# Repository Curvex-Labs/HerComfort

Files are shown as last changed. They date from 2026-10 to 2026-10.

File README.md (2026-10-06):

<p align="center">
  
</p>

# HerComfort

HerComfort is a wearable menstrual comfort and wellness solution designed to support women during emergencies, disasters, displacement, travel, relief-camp conditions, and other situations where access to conventional menstrual-care resources may be limited. During floods, earthquakes, evacuation, temporary shelters, or other emergency situations, women may have limited access to hot water, private resting spaces, continuous healthcare support, or convenient methods for managing menstrual discomfort. HerComfort aims to provide a portable, rechargeable, hands-free solution that combines controlled heating, vibration-based comfort, physiological monitoring, and local therapy control in a compact wearable belt.

The system integrates temperature monitoring, muscle-activity sensing, motion and posture awareness, BLE connectivity, and offline operation so that essential comfort functions can remain available even when continuous smartphone or internet access is not practical.
By combining wearable therapy, sensing, portability, and connected monitoring, HerComfort is intended to improve menstrual comfort, independence, and dignity for women in both everyday life and challenging emergency or disaster-response environments.

---

<p align="center">
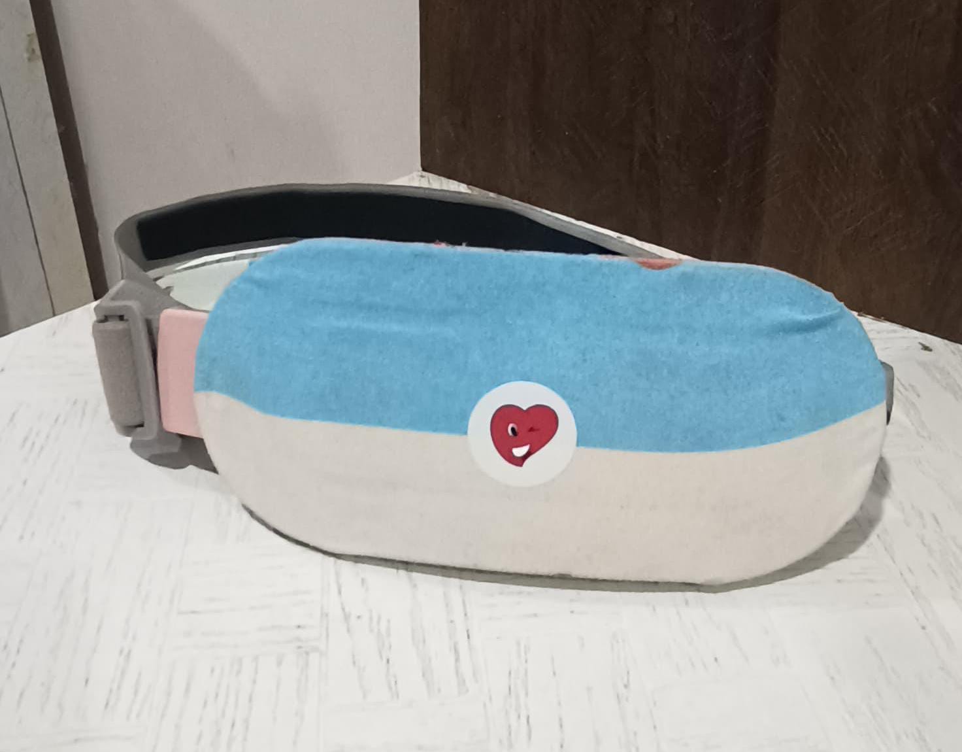
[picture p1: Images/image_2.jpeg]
  
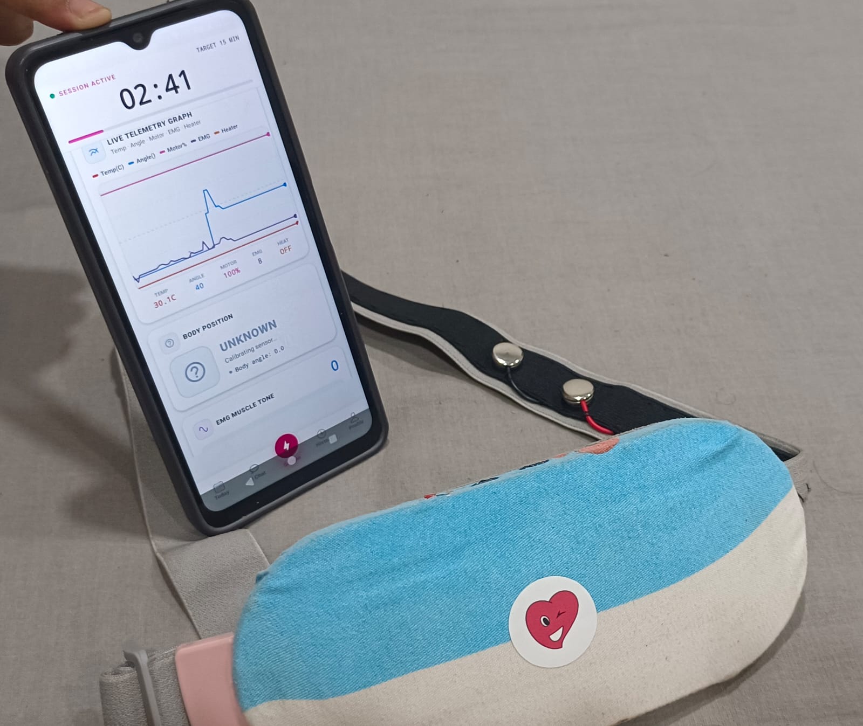
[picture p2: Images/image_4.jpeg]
  
</p>

<p align="center">
  <b>HerComfort Physical Prototype with Live Mobile Monitoring</b>
</p>

---

## Project Overview

HerComfort is being developed as an integrated wearable platform intended to support:

- Controlled heating therapy
- Vibration therapy
- EMG-based muscle activity monitoring
- Motion and posture sensing
- Temperature monitoring
- BLE connectivity
- Offline therapy control
- SOS / emergency support
- Battery-powered wearable operation

The final system is being designed around a compact custom PCB housed inside the curved front enclosure.

---

## Mechanical CAD Design

The refined HerComfort mechanical design was created in SolidWorks with a curved front therapy module, adjustable elastic belt, integrated controls, charging access, rear comfort surface, and dry EMG contact placement.

### Main Mechanical Dimensions

| Feature | Nominal Design |
|---|---|
| Therapy module | 185 mm long × 78 mm high |
| Maximum loft width | Approximately 80.1 mm |
| Overall depth envelope | Approximately 21.4 mm |
| Rear abdominal curvature | Approximately 3.5 mm sag across 160 mm |
| Rear comfort pad | Approximately 2.4 mm modeled section |
| Elastic strap | 48 mm wide × 3 mm thick |
| Charging opening | 10 × 3.8 mm USB-C access recess |
| Dry EMG contacts | Three 18 mm circular pads |
| EMG spacing | 30 mm center-to-center |
| Wearable circumference shown | Approximately 830 mm |

---

## Main CAD Views

### Front and Rear

<p align="center">
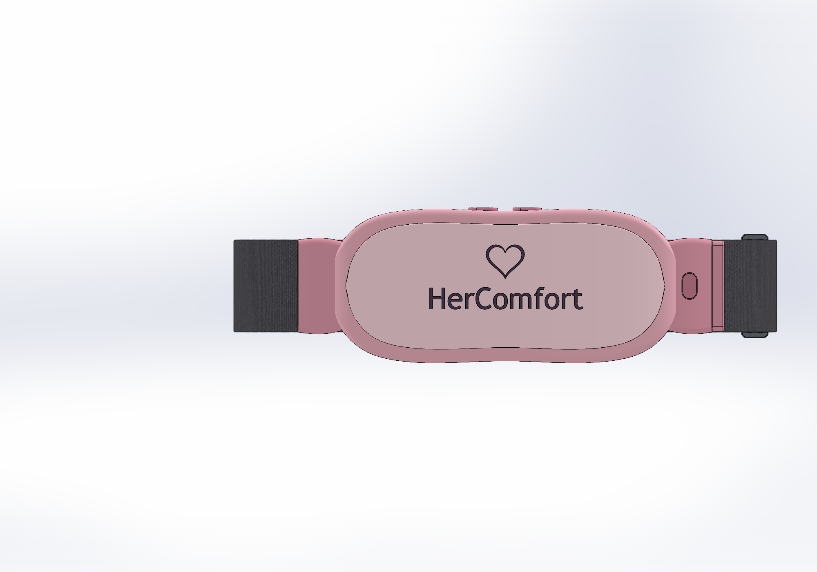
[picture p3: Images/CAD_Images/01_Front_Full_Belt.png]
HerComfort Front CAD View
  
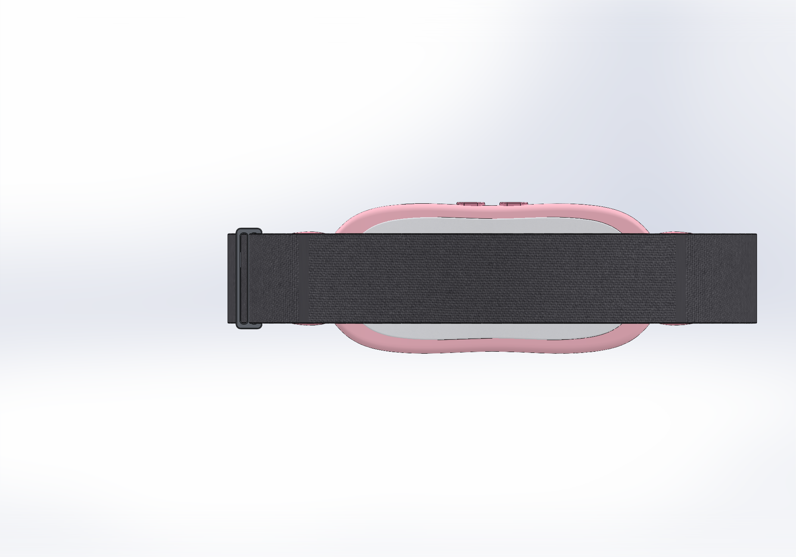
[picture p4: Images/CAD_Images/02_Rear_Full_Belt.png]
HerComfort Rear CAD View
  
</p>

### Isometric and Inner View

<p align="center">
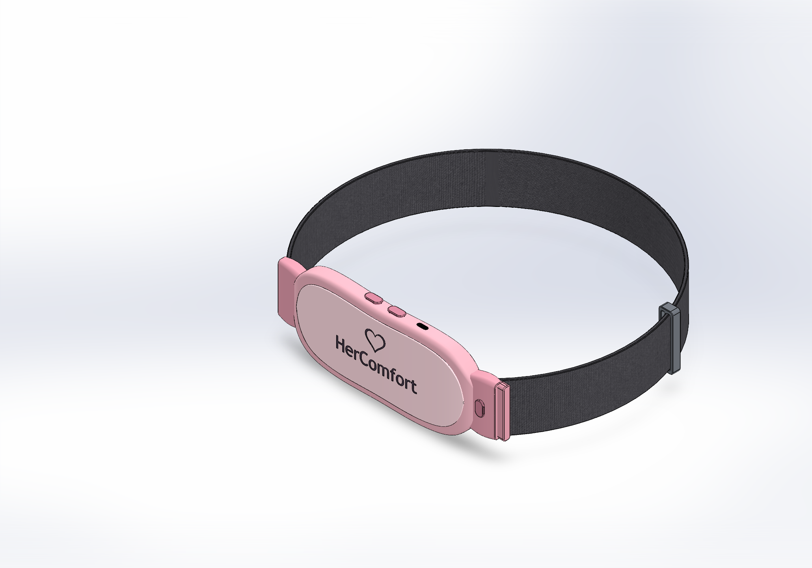
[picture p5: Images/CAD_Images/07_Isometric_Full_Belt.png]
HerComfort Isometric CAD View
  
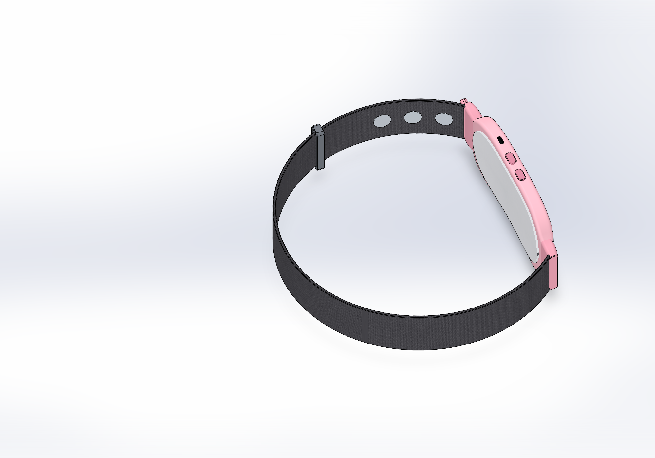
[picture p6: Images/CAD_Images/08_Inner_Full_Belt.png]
HerComfort Inner CAD View
  
</p>

---

## EMG Contact Design

HerComfort includes three dry EMG contact points on the skin-facing inner side of the belt.

The contacts are designed as:

- 18 mm circular metallic pads
- Arranged in one row
- 30 mm center-to-center spacing
- Positioned near the front-right inner belt region
- Integrated into the wearable surface

The intended signal chain is:

**Dry EMG electrodes → Muscle BioAmp Candy → Signal conditioning → ESP32-C6 ADC**

---

## Electronics Development

HerComfort currently uses a custom KiCad-designed carrier PCB that integrates the existing prototype modules into a compact and serviceable wearable electronics platform.

The present carrier board interfaces:

- Seeed Studio XIAO ESP32C6
- MPU6050 IMU
- Muscle BioAmp Candy
- DS18B20 temperature sensor
- TP4056 charging module
- Mini-360 DC-DC converter
- Heating pad
- Vibration motor
- AO3400A MOSFET switching stages
- Physical Mode button
- Li-ion battery

This carrier board represents the current functional prototype electronics.

A future fully integrated HerComfort PCB is planned to replace the removable modules with dedicated onboard circuitry and additional safety, sensing, power-management, and protection features.

---

## PCB Carrier Board

A custom HerComfort carrier PCB has been designed in KiCad to replace loose prototype wiring and provide a cleaner, compact hardware platform for the current working electronics.

The carrier board supports:

- Seeed Studio XIAO ESP32C6
- MPU6050 IMU
- Muscle BioAmp Candy
- DS18B20 temperature sensor
- TP4056 Li-ion charging module
- Mini-360 DC-DC converter
- AO3400A MOSFET heater control
- AO3400A MOSFET vibration motor control
- 1N5819 flyback protection diode
- Mode push button
- Heating pad connection
- Vibration motor connection
- Li-ion battery connection

The removable modules are mounted using female headers so that the controller and sensor modules can be replaced or serviced without replacing the complete PCB.
Images/PCB_Images/PCB_Back.png
### PCB Schematic

<p align="center">
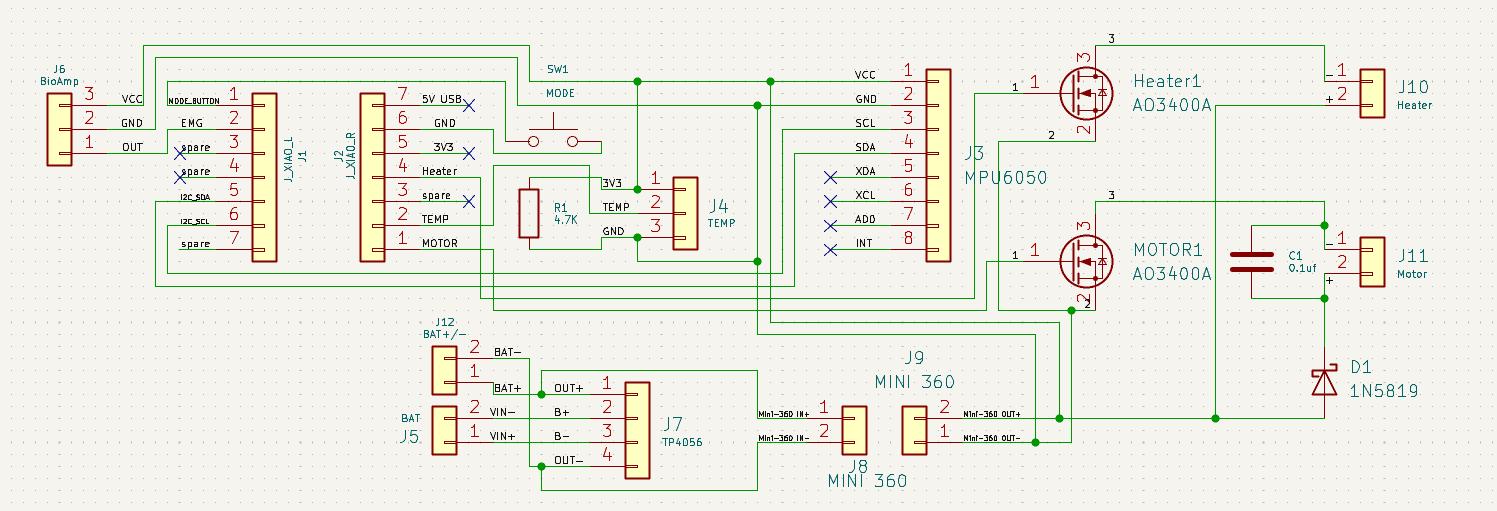
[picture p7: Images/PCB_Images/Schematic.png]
HerComfort PCB Schematic
  
</p>

### PCB Front and Back Views

<p align="center">
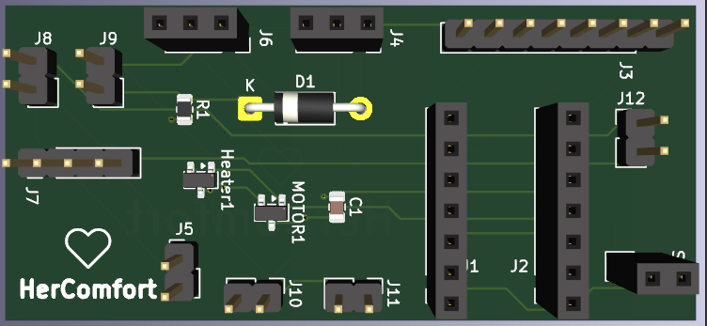
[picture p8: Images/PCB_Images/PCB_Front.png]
HerComfort PCB Front View
  
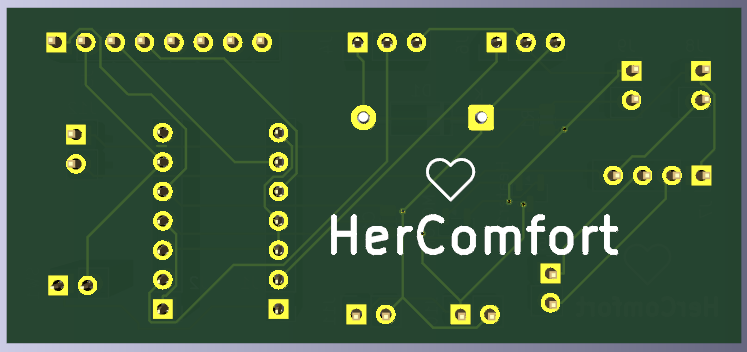
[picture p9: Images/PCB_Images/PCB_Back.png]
HerComfort PCB Back View
  
</p>

### PCB Routing

<p align="center">
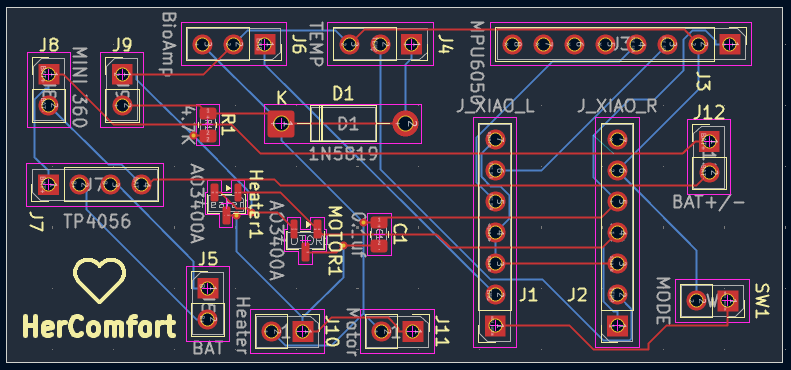
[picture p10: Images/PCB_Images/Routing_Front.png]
HerComfort PCB Front Routing
  
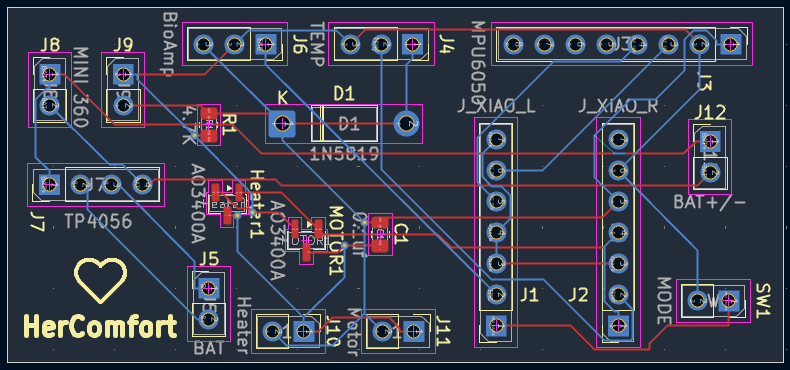
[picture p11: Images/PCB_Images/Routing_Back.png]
HerComfort PCB Back Routing
  
</p>

### Main GPIO Mapping

| Function | XIAO Pin | ESP32-C6 GPIO |
|---|---:|---:|
| Mode Button | D0 | GPIO0 |
| EMG Signal | D1 | GPIO1 |
| I²C SDA | D4 | GPIO22 |
| I²C SCL | D5 | GPIO23 |
| Vibration Motor | D7 | GPIO17 |
| DS18B20 Temperature | D8 | GPIO19 |
| Heating Pad | D10 | GPIO18 |

### Power Architecture

```text
3.7 V Li-ion Battery
        │
        ▼
      TP4056
        │
        ├────────► XIAO ESP32C6 battery input
        │
        ▼
     Mini-360
        │
        ▼
 Regulated therapy rail
        │
        ├────────► Heating Pad
        │
        └────────► Vibration Motor

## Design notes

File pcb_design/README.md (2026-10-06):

# HerComfort PCB Carrier Board

Custom raw carrier PCB developed for the HerComfort wearable menstrual comfort belt.

## PCB Overview

The carrier board integrates and connects the main HerComfort hardware modules:

- Seeed Studio XIAO ESP32C6
- MPU6050 IMU
- Muscle BioAmp Candy
- DS18B20 temperature sensor
- TP4056 Li-ion charging module
- Mini-360 buck converter
- AO3400A MOSFET heater control
- AO3400A MOSFET vibration motor control
- 1N5819 flyback diode
- Mode push button
- Li-ion battery
- Heating pad
- Vibration motor

## Schematic

HerComfort PCB Schematic

## PCB Front View

PCB Front

## PCB Back View

PCB Back

## Front Routing

Front Routing

## Back Routing

Back Routing

## Main GPIO Mapping

| Function | XIAO Pin | GPIO |
|---|---|---|
| Mode Button | D0 | GPIO0 |
| EMG | D1 | GPIO1 |
| I2C SDA | D4 | GPIO22 |
| I2C SCL | D5 | GPIO23 |
| Motor | D7 | GPIO17 |
| Temperature | D8 | GPIO19 |
| Heater | D10 | GPIO18 |

## Power Architecture

```text
Li-ion Battery
      |
    TP4056
      |
 Protected Battery Output
      |
      +---- XIAO ESP32C6
      |
      +---- Mini-360
               |
              3.3V
               |
        Heater + Motor

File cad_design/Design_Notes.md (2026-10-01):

# HerComfort refined external concept

This model follows the supplied correction brief and real product photos. It contains only exterior geometry. The screen in the reference product is deliberately omitted.

## Design dimensions (mm)

| Feature | Nominal design |
|---|---|
| Therapy module | 185 long × 78 high nominal; approximately 80.1 mm maximum loft width and 21.4 mm overall curved depth envelope |
| Abdominal curvature | Approximately 3.5 mm rear-pad sag across 160 mm |
| Rear comfort pad | 2.4 mm modeled section; approximately 1.6–2.3 mm exposed; gray textile appearance |
| Top controls | Two 15 × 8 mm pill buttons; approximately 1.7 mm exposed height |
| Button spacing | 8 mm clear gap |
| Charging opening | One 10 × 3.8 mm rounded USB-C access recess |
| Elastic strap | One continuous solid band, 48 mm wide × 3 mm thick |
| Wearable size shown | Approximately 830 mm circumference including the module |
| Connection | Fixed left anchor; right receiver, strap connector and raised release button |
| Adjustment | One simple two-slot slider |
| Dry EMG contacts | Three 18 mm circular silver pads on the inner front-right fabric |
| EMG sensing pair | 30 mm center-to-center along the strap centerline |
| EMG reference spacing | 30 mm from the nearer sensing pad; approximately 45 mm from the sensing pair midpoint |
| EMG contact profile | 1 mm total pad thickness, embedded into the 3 mm band; 0.35 mm maximum center projection; 0.25 mm edge fillets |

The main housing, front panel and contact pad use lofted sections with a gradual symmetric bow. The controls, connector details and slider use rounded sketches, extrusions and small fillets. The band is a single extruded curved profile behind the module.

Profile connection points are aligned consistently across each loft to preserve a clean capsule outline. The housing width adjusts slightly from the nominal sketch dimensions as the loft interpolates between sections.

## Verification

The final model rebuilt successfully. All 11 solid bodies returned zero errors from SolidWorks' body check. No feature errors were reported. The native and STEP exports both saved successfully with zero errors; the native save also reported zero warnings. The model includes centered HerComfort branding in muted plum on the lighter front panel. The editable wordmark and recreated heart use flush surface regions that follow the curved panel; they add no enclosure thickness. The branded model also rebuilt without feature errors and all 11 bodies passed the native body check. Native and STEP files saved with zero errors.

The six original views were inspected for the strap continuity, capsule outline, top controls, rear contact surface and detachable connector exterior.

## Files

- `HerComfort_Refined.SLDPRT`: editable SolidWorks 2024 multibody part with named modeling features.
- `HerComfort_Refined.step`: neutral solid geometry export.
- `Views/`: nine model views, including a front branding view, covering the front, rear pad, top controls, continuous band, detachable connection, abdominal curvature and inner EMG placement.
- `Appearances/`: rose finishes and gray fabric assets used by the native model. Keep these files together if moving the model. STEP primarily preserves geometry; use the native file for the intended appearance.

This is an exterior industrial design concept. The push-release connector and adjustment slider represent their visible form and connection arrangement. Their internal mechanisms, operation, structural performance, manufacturing clearances and heating performance are outside this model's scope.

## Inner dry EMG electrode update

The three contacts are separate editable solid bodies with a satin silver appearance. All three sit on the skin-facing side of the soft elastic band immediately beyond the right-hand pink connector. Their contact faces point inward toward the abdomen. All three pad centers lie on the middle of the 48 mm band width, forming one row along the curved inner fabric. Adjacent pads are evenly spaced at 30 mm center-to-center, leaving approximately 12 mm of fabric between their 18 mm diameters. The reference is approximately 45 mm from the sensing pair midpoint. This row replaces the previous triangular arrangement. Each pad remains tangent to its local inner fabric surface.

Each 18 mm pad is tangent to the local inner curve and extends into the fabric. Its central contact surface projects inward by 0.35 mm; projection reduces toward its rounded perimeter. The 1 mm pad remains within the strap thickness and does not emerge on the outside. The appearance represents a metallic contact surface; no wiring, sensors behind the contact, or electronics were modeled.

All 14 final solid bodies passed SolidWorks body checks with zero errors. No feature errors were reported. The native model and STEP geometry saved with zero errors, and the native save reported zero warnings. The recorded bounding boxes of all 11 pre-existing bodies match those before this update. Existing branding, colors, strap geometry, controls and proportions are preserved.

`Views/08_Inner_Right_EMG_Electrodes.png` shows all three contacts clearly beside the connector and control pod. `Views/09_Inner_Belt_EMG_Overview.png` verifies the contacts are on the inside of the wearable loop. These are exterior CAD contact representations; actual skin contact and EMG measurement performance were not tested.

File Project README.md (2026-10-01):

# HerComfort

<p align="center">
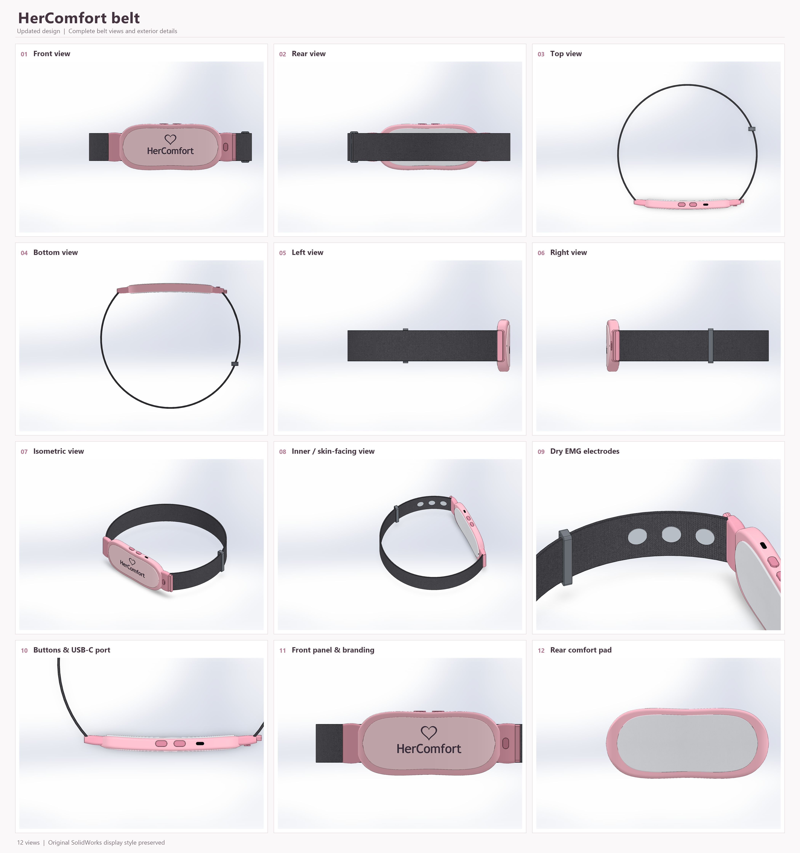
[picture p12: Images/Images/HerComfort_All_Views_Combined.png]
HerComfort Overview
  
</p>

HerComfort is a wearable health companion designed for menstrual comfort, physiological monitoring, local therapy control, and connected health support.

The project combines wearable mechanical design, custom electronics, sensing, therapy control, BLE connectivity, and embedded intelligence into a compact belt-based system.

---

## Project Status

HerComfort is currently under active development.

### Completed
- Refined wearable industrial design
- Curved front therapy/control enclosure
- Adjustable elastic belt architecture
- Dry EMG contact placement
- SolidWorks native model
- STEP export
- Multiple verified product views
- Mechanical body checks completed successfully

### In Progress
- Custom HerComfort main PCB
- Bare ESP32-C6 integration
- Integrated Muscle BioAmp Candy analog front-end
- Heating pad control
- Dual vibration motor control
- IMU integration
- Temperature sensing
- Battery charging and power management
- BLE firmware
- Mobile application integration

---

## Product Views

<p align="center">
  
  
</p>

<p align="center">
  
  
</p>

---

## Design Details

<p align="center">
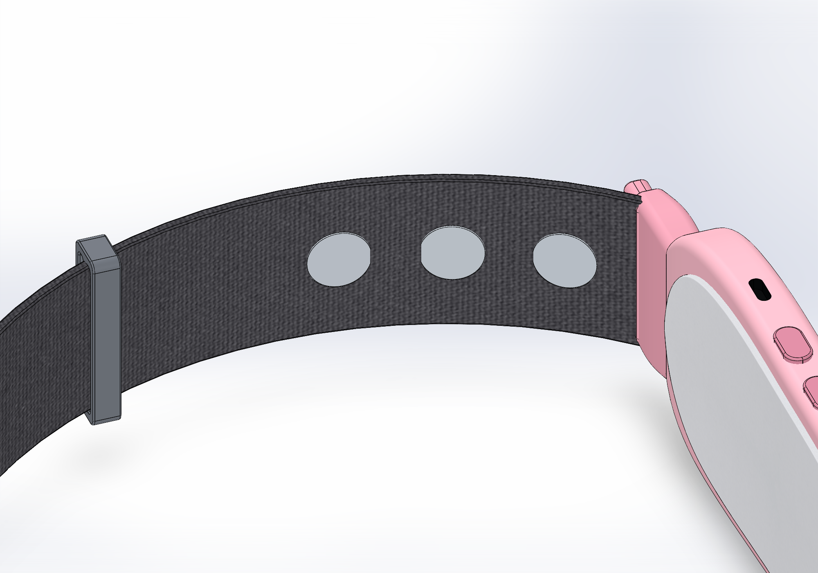
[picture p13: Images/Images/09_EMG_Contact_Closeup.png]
  
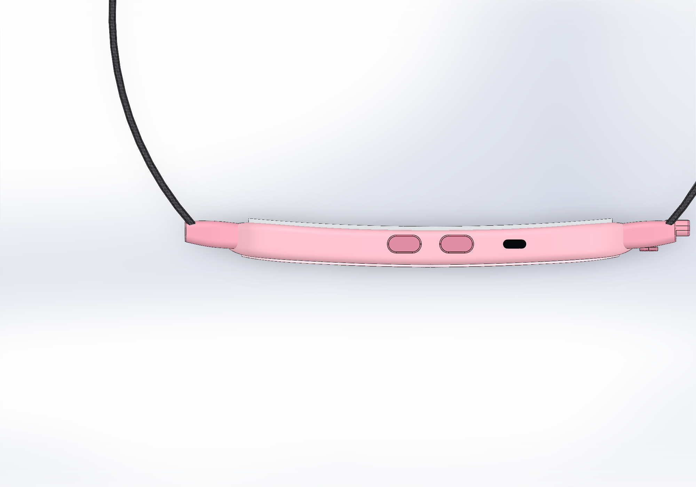
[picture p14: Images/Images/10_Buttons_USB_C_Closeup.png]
  
</p>

<p align="center">
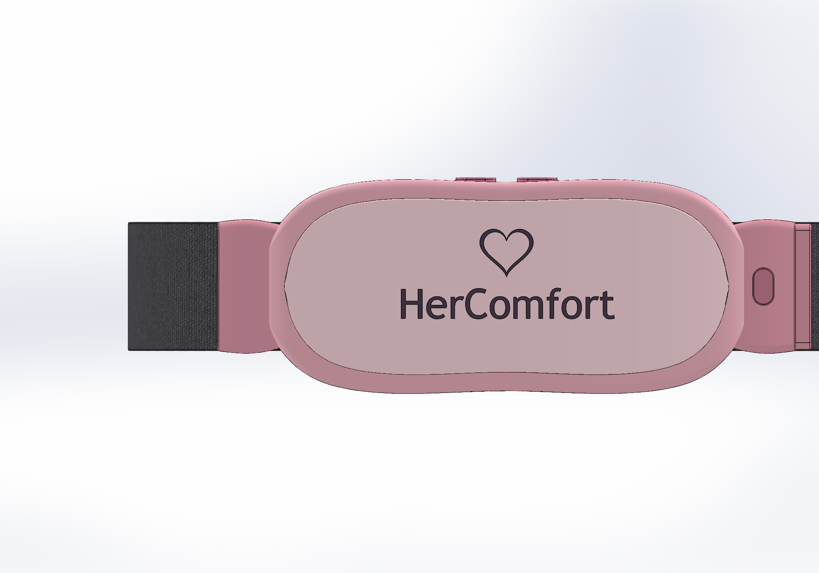
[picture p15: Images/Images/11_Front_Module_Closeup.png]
  
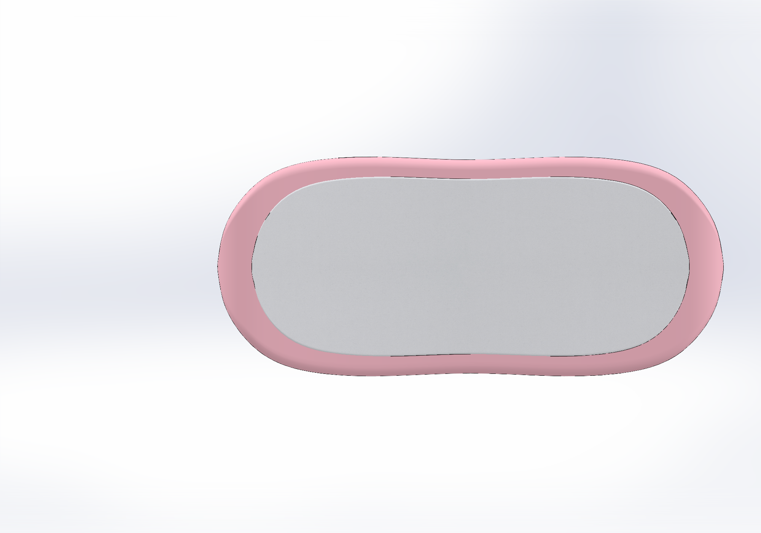
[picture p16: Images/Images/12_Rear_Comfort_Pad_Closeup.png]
  
</p>

---

## Mechanical Design

The current HerComfort model represents the refined external industrial design.

### Main Dimensions

| Feature | Nominal Design |
|---|---|
| Therapy module | 185 mm long × 78 mm high |
| Maximum curved width | Approximately 80.1 mm |
| Overall depth envelope | Approximately 21.4 mm |
| Rear abdominal curvature | Approximately 3.5 mm sag across 160 mm |
| Rear comfort pad | Approximately 2.4 mm modeled section |
| Strap width | 48 mm |
| Strap thickness | 3 mm |
| USB-C access opening | 10 × 3.8 mm |
| Dry EMG contacts | 3 × 18 mm circular pads |
| EMG spacing | 30 mm center-to-center |

The current enclosure model is primarily an exterior product-design concept. Internal electronics packaging, PCB mounting, battery space, and detailed internal mechanical clearances are being integrated alongside the electronics design.

---

## Dry EMG Contact Layout

HerComfort includes three dry EMG contact locations on the skin-facing side of the inner belt.

- Three circular metallic contact pads
- 18 mm diameter each
- Positioned in one row
- 30 mm center-to-center spacing
- Located immediately beside the right-side connector area
- Embedded into the inner elastic belt surface

The electrodes are intended to connect to the integrated EMG analog front-end on the main HerComfort PCB.

---

## Electronics Architecture

The final HerComfort system is intended to use one compact custom main PCB inside the front enclosure.

The PCB will contain or control:

- Bare ESP32-C6
- Integrated Muscle BioAmp Candy analog front-end
- 6-axis IMU
- Therapy-zone temperature sensing
- Heating pad driver
- Two independent vibration motor drivers
- Physical control buttons
- RGB/status indication
- USB-C charging and programming
- Battery protection
- Battery monitoring
- BLE communication
- Safety and fault-control circuitry

The ESP32-C6 acts as the central controller for the complete wearable system.

---

## EMG Front-End

The EMG section is based on the Muscle BioAmp Candy architecture and is being integrated directly onto the HerComfort main PCB.

The signal chain is:

**Dry EMG electrodes → input network → amplification → band-pass filtering → ADC conditioning → ESP32-C6 ADC**

The original Candy topology uses:

- Quad op-amp architecture
- Nominal gain around ×2420
- Band-pass range approximately 72–720 Hz
- Buffered reference voltage
- Differential EMG acquisition

The final integrated version is being adapted carefully for direct use with the ESP32-C6 ADC.

---

## Therapy System

HerComfort is designed to provide two forms of local therapy:

### Heating Therapy
A flexible heating pad is intended to provide controlled warmth to the lower-abdominal region.

The heating subsystem will include:

- Closed-loop temperature control
- PWM-based heater power control
- Temperature feedback
- Over-temperature protection
- Hardware safety cutoff
- Fail-safe OFF behavior

### Vibration Therapy
Two independently controlled vibration motors are planned for the therapy region.

Supported control modes may include:

- Continuous vibration
- Pulse vibration
- Variable intensity
- Patterned/harmonic vibration

---

## Physical Controls

The product is planned around three dedicated physical control functions:

1. Power
2. Offline Therapy
3. SOS / Emergency

The enclosure will be updated so the physical control geometry aligns directly with the PCB switches.

---

## Connectivity

HerComfort uses BLE communication for interaction with the mobile application.

Planned functions include:

- Therapy control
- Sensor monitoring
- Battery status
- Session information
- Device status
- Offline operation
- Emergency/SOS support

Essential local functions are designed to remain available without continuous internet connectivity.

---

## Power System

The power architecture is under active design.

The final battery selection will be based on:

- Heating-pad current
- Dual vibration-motor current
- ESP32-C6 peak consumption
- EMG analog front-end consumption
- IMU
- Temperature sensor
- BLE activity
- Power-conversion losses
- Required runtime

Battery capacity will be finalized only after the complete load budget is locked.

---

## Repository Structure

### `Mechanical/`
Contains the mechanical design files including:

- SolidWorks model
- STEP export
- Mechanical design assets
- Product geometry

### `Images/`
Contains:

- Front view
- Rear view
- Top view
- Bottom view
- Left view
- Right view
- Isometric view
- Inner belt view
- EMG contact close-up
- Button and USB-C close-up
- Front module close-up
- Rear comfort pad close-up
- Combined product view

### `Electronics/`
Will contain:

- KiCad project
- Schematic
- PCB layout
- BOM
- Gerber files
- Pick-and-place files
- PCB renders

### `Documentation/`
Will contain:

- System architecture
- Design specifications
- Electrical documentation
- Testing notes
- Development records

---

## Tools Used

### Mechanical
- SolidWorks 2024

### Electronics
- KiCad

### Embedded System
- ESP32-C6
- Embedded C/C++

### Communication
- Bluetooth Low Energy

---

## Development Notes

HerComfort is being developed as an integrated wearable system rather than a collection of separate development modules.

The design approach focuses on:

- Compact custom electronics
- Wearable comfort
- Reliable sensing
- Controlled therapy
- Low-noise EMG acquisition
- Safe power management
- BLE connectivity
- Manufacturable PCB design
- Enclosure-integrated electronics

---

## Current Development Roadmap

1. Finalize electronic components
2. Complete HerComfort schematic
3. Complete PCB placement and routing
4. Match PCB to enclosure geometry
5. Finalize battery and power architecture
6. Assemble prototype PCB
7. Validate sensing and therapy
8. Test BLE and offline control
9. Perform thermal and electrical safety testing
10. Refine for manufacturing

---

## Disclaimer

HerComfort is currently a prototype-stage engineering project.

The present mechanical model represents the product design concept and enclosure geometry. Electronic, thermal, sensing, and safety functions are still under development and validation.

The project does not claim medical certification or clinical diagnostic capability at its current stage.

---

## Team

Developed as part of the HerComfort wearable health project for innovation and prototype development.

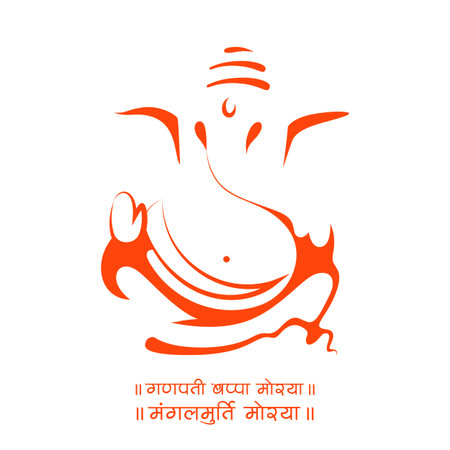
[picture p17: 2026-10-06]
pcb_design/Images/Lord_Ganesha.jpg

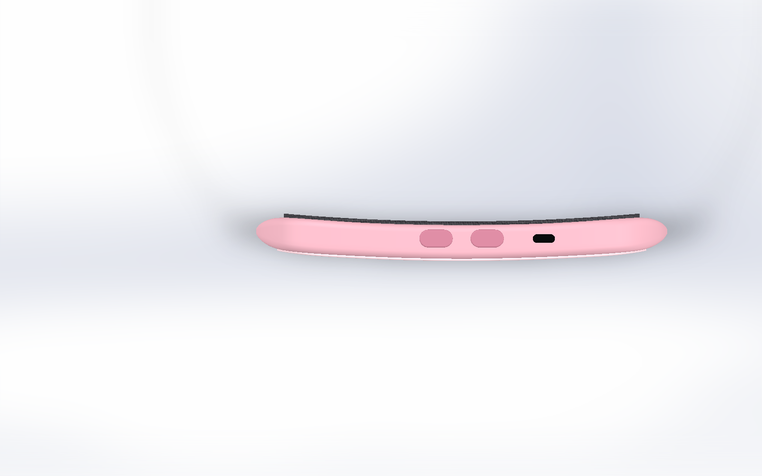
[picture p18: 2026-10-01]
cad_design/Views/03_Top_Buttons_USB_C.png

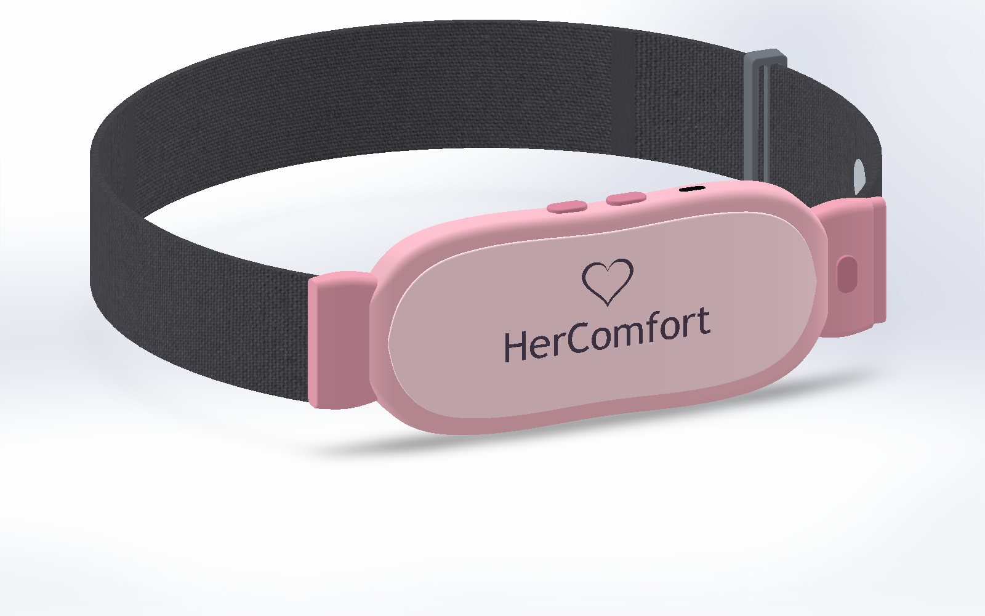
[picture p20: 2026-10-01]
cad_design/Views/01_Front_Isometric.png

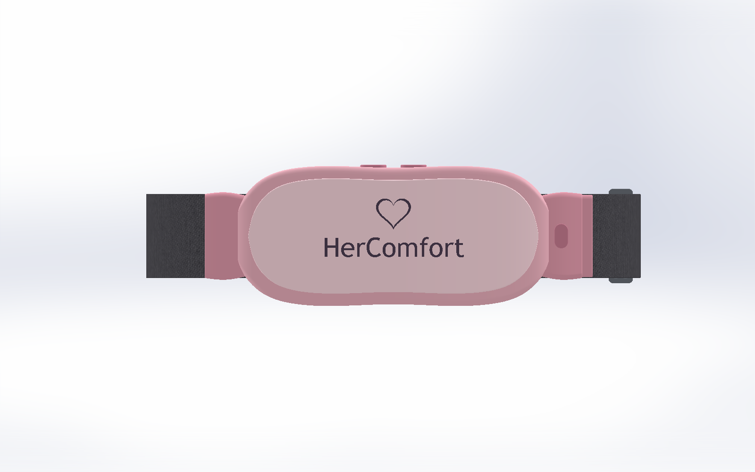
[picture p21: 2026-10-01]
cad_design/Views/07_Front_Branding.png

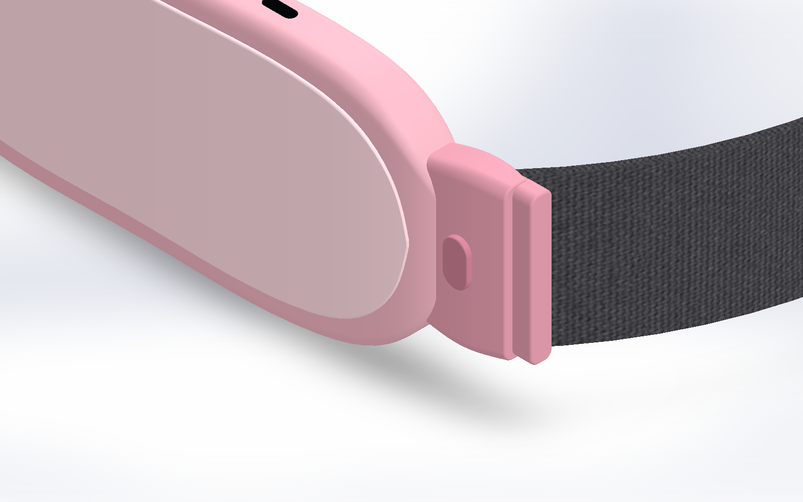
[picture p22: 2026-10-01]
cad_design/Views/05_Detachable_Connector_Closeup.png

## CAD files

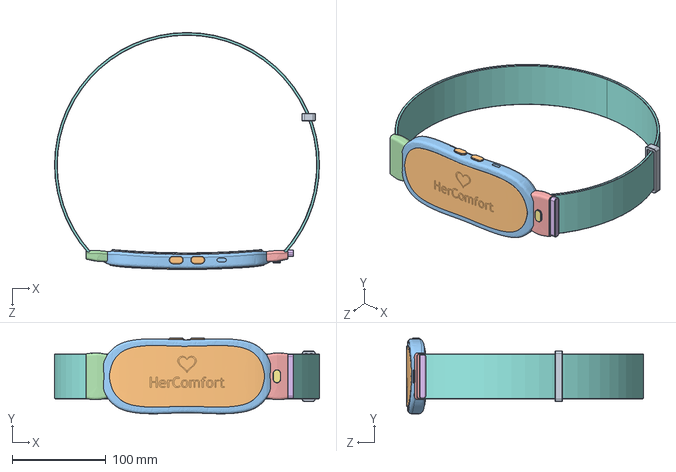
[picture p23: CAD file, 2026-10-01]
cad_design/HerComfort_Refined.step
283.0 x 80.7 x 253.2 mm

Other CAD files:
cad_design/HerComfort_Refined.SLDPRT

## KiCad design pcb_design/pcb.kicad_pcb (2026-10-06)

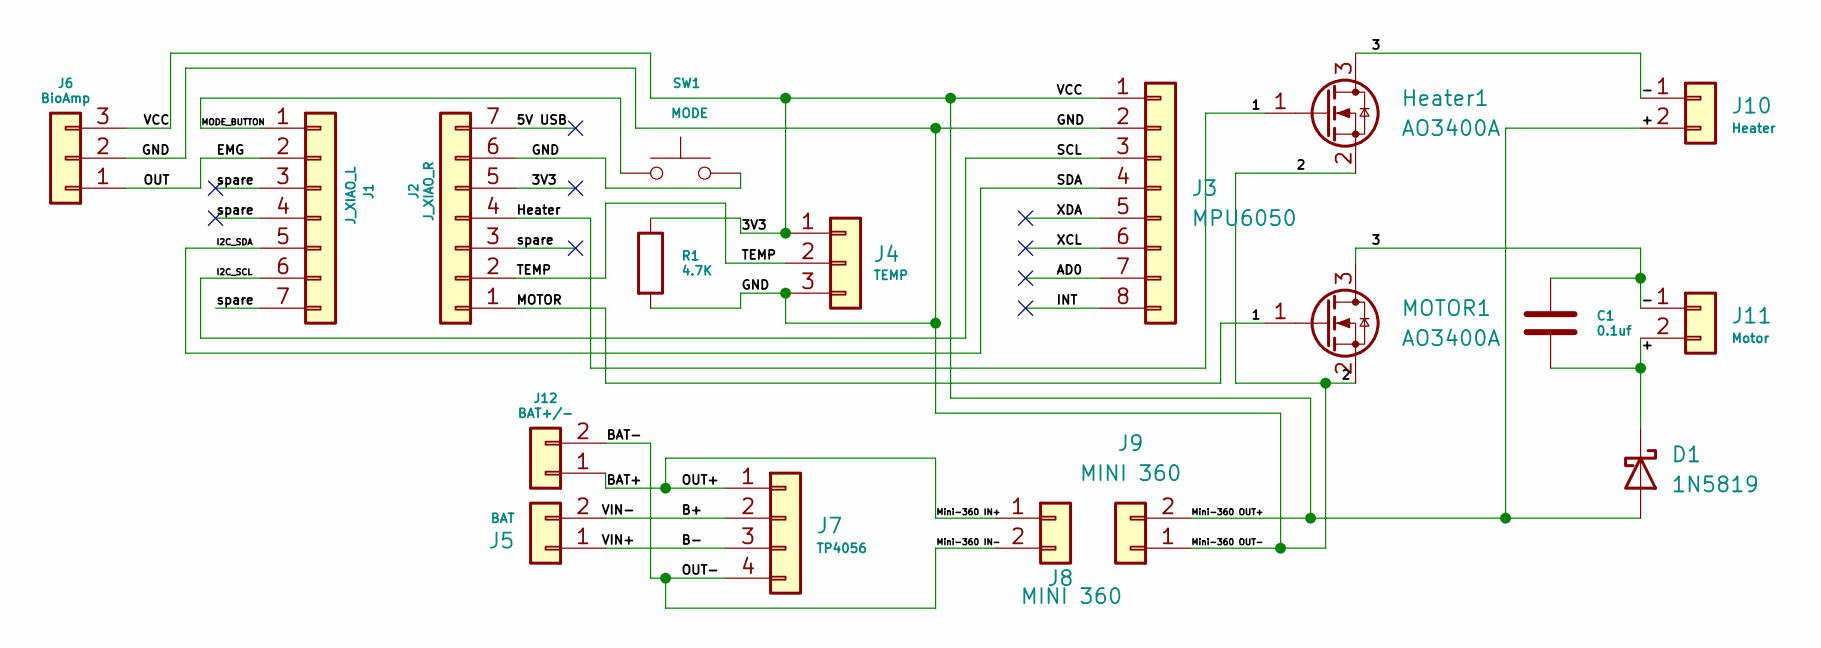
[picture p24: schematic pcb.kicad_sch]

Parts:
C1: 0.1uf; C_0805_2012Metric
D1: 1N5819; D_DO-41_SOD81_P10.16mm_Horizontal
Heater1: AO3400A; SOT-23
J1: J_XIAO_L; PinSocket_1x07_P2.54mm_Vertical
J2: J_XIAO_R; PinSocket_1x07_P2.54mm_Vertical
J3: MPU6050; PinHeader_1x08_P2.54mm_Vertical
J4: TEMP; PinSocket_1x03_P2.54mm_Vertical
J5: BAT; PinHeader_1x02_P2.54mm_Vertical
J6: BioAmp; PinSocket_1x03_P2.54mm_Vertical
J7: TP4056; PinHeader_1x04_P2.54mm_Vertical
J8, J9: MINI 360; PinHeader_1x02_P2.54mm_Vertical
J10: Heater; PinHeader_1x02_P2.54mm_Vertical
J11: Motor; PinHeader_1x02_P2.54mm_Vertical
J12: BAT+/-; PinHeader_1x02_P2.54mm_Vertical
MOTOR1: AO3400A; SOT-23
R1: 4.7K; R_0805_2012Metric
SW1: MODE; PinSocket_1x02_P2.54mm_Vertical

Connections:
/1: Heater1.1 (G), J2.1, J2.4, MOTOR1.1 (G)
/2: Heater1.2 (S), J2.6, J3.2, J4.3, J6.2, J9.1, MOTOR1.2 (S), R1.2, SW1.2
/5V USB: J2.7
/+: C1.1, D1.1 (K), D1.2 (A), J2.5, J3.1, J4.1, J6.3, J9.2, J10.2, J11.2, R1.1
/-: C1.2, Heater1.3 (D), J10.1, J11.1, MOTOR1.3 (D)
/AD0: J3.7
/B+: J5.2, J7.2
/B-: J5.1, J7.3
/BAT+: J7.1, J8.1, J12.1
/BAT-: J7.4, J8.2, J12.2
/EMG: J1.2, J6.1
/I2C_SCL: J1.6, J3.3
/I2C_SDA: J1.5, J3.4
/INT: J3.8
/MODE_BUTTON: J1.1, SW1.1
/TEMP: J2.2, J4.2
/XCL: J3.6
/XDA: J3.5
/spare: J1.3, J1.4, J1.7, J2.3

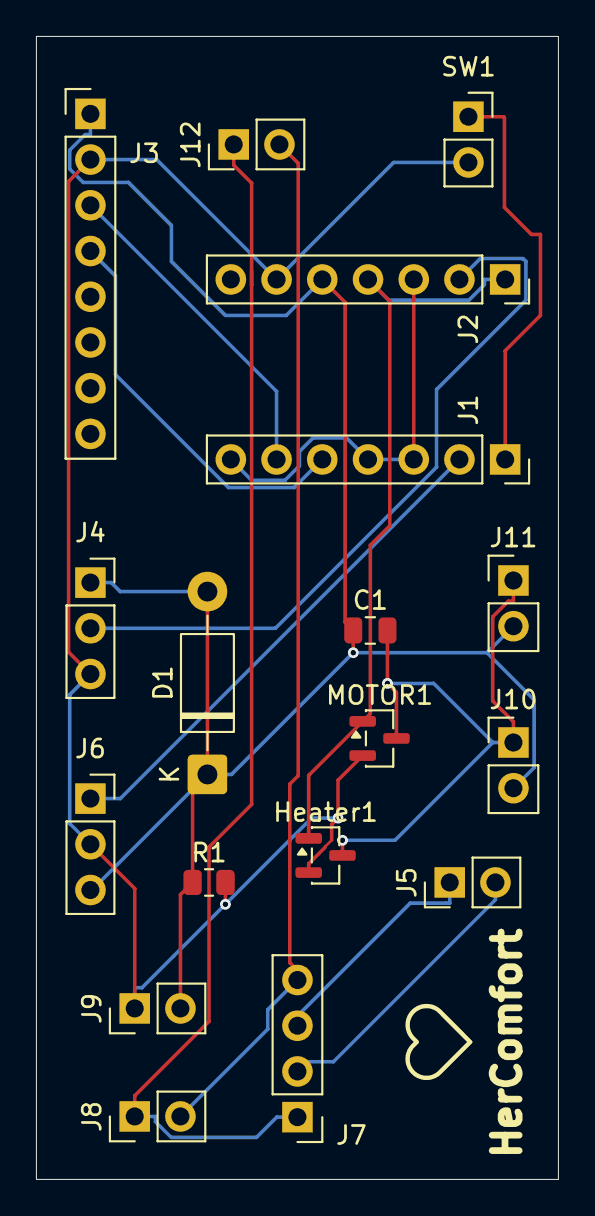
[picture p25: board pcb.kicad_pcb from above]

Board: 2 copper layers, 29.0 x 63.5 mm, 18 parts (0 on the bottom side), 14 nets.

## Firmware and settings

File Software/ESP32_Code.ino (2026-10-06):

#include <Arduino.h>
#include <Wire.h>
#include <math.h>
#include <NimBLEDevice.h>

#include <OneWireNg_CurrentPlatform.h>
#include <drivers/DSTherm.h>
#include <utils/Placeholder.h>

// =====================================================
// HER COMFORT - XIAO ESP32-C6
// =====================================================

// PIN MAP
#define MODE_BUTTON_PIN 0     // D0 / GPIO0
#define EMG_PIN 1             // D1 / GPIO1
#define SDA_PIN 22            // D4 / GPIO22
#define SCL_PIN 23            // D5 / GPIO23
#define MOTOR_PIN 17          // D7 / GPIO17
#define TEMP_PIN 19           // D8 / GPIO19
#define HEATER_PIN 18         // D10 / GPIO18


// =====================================================
// EMG
// =====================================================

#define EMG_SAMPLE_RATE 500
#define EMG_BUFFER_SIZE 128

int emgCircularBuffer[EMG_BUFFER_SIZE];
int emgDataIndex = 0;
long emgSum = 0;

int latestEMG = 0;

unsigned long lastEMGSample = 0;


// =====================================================
// HEATER
// =====================================================

const float HEATER_ON_TEMP = 37.0f;
const float HEATER_OFF_TEMP = 38.0f;

const float HEATER_HARD_CUTOFF = 40.0f;

bool heaterOn = false;


// =====================================================
// MOTOR
// =====================================================

#define MOTOR_PWM_FREQ 5000
#define MOTOR_PWM_RESOLUTION 8

const int CONTINUOUS_PWM = 255;
const int PULSE_PWM = 255;

const int HARMONIC_MIN_PWM = 200;
const int HARMONIC_MAX_PWM = 255;

const unsigned long PULSE_ON_TIME = 3000;
const unsigned long PULSE_OFF_TIME = 2000;

const unsigned long HARMONIC_PERIOD = 4000;

const unsigned long MODE_CHANGE_GAP = 1000;


// =====================================================
// MOTOR MODE
// =====================================================

enum MotorMode
{
  MOTOR_OFF,
  MOTOR_CONTINUOUS,
  MOTOR_PULSE,
  MOTOR_HARMONIC
};

MotorMode motorMode = MOTOR_OFF;


// =====================================================
// MOTOR STATE
// =====================================================

bool previousButtonState = HIGH;

unsigned long lastButtonPress = 0;

const unsigned long BUTTON_DEBOUNCE = 250;

unsigned long pulseTimer = 0;

bool pulseMotorOn = true;

unsigned long modeChangeTime = 0;

bool modeGapActive = false;

unsigned long harmonicStartTime = 0;


// =====================================================
// MPU6500
// =====================================================

#define MPU_ADDR 0x68

#define MPU_WHO_AM_I       0x75
#define MPU_PWR_MGMT_1     0x6B
#define MPU_CONFIG         0x1A
#define MPU_GYRO_CONFIG    0x1B
#define MPU_ACCEL_CONFIG   0x1C
#define MPU_ACCEL_CONFIG2  0x1D
#define MPU_ACCEL_XOUT_H   0x3B

#define MPU6500_ID 0x70


// =====================================================
// MPU SCALE
// =====================================================

const float ACCEL_SCALE = 16384.0f;

const float GYRO_SCALE = 131.0f;


// =====================================================
// MPU CALIBRATION
// =====================================================

const int CALIBRATION_SAMPLES = 1000;

float gyroBiasX = 0.0f;
float gyroBiasY = 0.0f;
float gyroBiasZ = 0.0f;

float referenceAx = 0.0f;
float referenceAy = 0.0f;
float referenceAz = 1.0f;

bool calibrationRunning = false;


// =====================================================
// ACCEL LOW PASS FILTER
// =====================================================

const float ACCEL_LPF_CUTOFF_HZ = 5.0f;

float filteredAx = 0.0f;
float filteredAy = 0.0f;
float filteredAz = 1.0f;

bool accelFilterInitialized = false;


// =====================================================
// SENSOR FUSION
// =====================================================

float q0 = 1.0f;
float q1 = 0.0f;
float q2 = 0.0f;
float q3 = 0.0f;

const float FUSION_KP = 0.40f;

const float FUSION_KI = 0.0f;

float integralFBx = 0.0f;
float integralFBy = 0.0f;
float integralFBz = 0.0f;

unsigned long lastFusionMicros = 0;


// =====================================================
// POSITION
// =====================================================

const float UPRIGHT_MAX_ANGLE = 45.0f;

const float LYING_MIN_ANGLE = 70.0f;


// =====================================================
// WALKING
// =====================================================

const float WALK_AXIS_THRESHOLD = 5.0f;

const float WALK_GYRO_THRESHOLD = 10.0f;

const float WALK_ACCEL_DELTA = 0.04f;


// =====================================================
// POSITION CONFIRMATION
// =====================================================

const unsigned long UPRIGHT_CONFIRM_MS = 1000;
const unsigned long LYING_CONFIRM_MS = 1500;
const unsigned long WALK_CONFIRM_MS = 700;


// =====================================================
// MPU RAW VALUES
// =====================================================

int16_t rawAx = 0;
int16_t rawAy = 0;
int16_t rawAz = 0;

int16_t rawGx = 0;
int16_t rawGy = 0;
int16_t rawGz = 0;


// =====================================================
// BODY ANGLE
// =====================================================

float latestBodyAngle = 0.0f;


// =====================================================
// POSITION ENUM
// =====================================================

enum PositionState
{
  POSITION_UNKNOWN,
  POSITION_UPRIGHT,
  POSITION_LYING,
  POSITION_WALKING
};

PositionState currentPosition = POSITION_UNKNOWN;

PositionState candidatePosition = POSITION_UNKNOWN;

unsigned long candidateStartTime = 0;


// =====================================================
// TEMPERATURE
// =====================================================

OneWireNg_CurrentPlatform oneWire(
  TEMP_PIN,
  false
);

DSTherm ds18b20(
  oneWire
);

Placeholder<DSTherm::Scratchpad> scratchpad;

float latestTemperature = 0.0f;

bool temperatureValid = false;

bool tempConversionRunning = false;

unsigned long tempConversionStart = 0;

unsigned long lastTempRequest = 0;

#define TEMP_CONVERSION_TIME 750


// =====================================================
// BLE
// =====================================================

#define SERVICE_UUID \
"12345678-1234-1234-1234-123456789000"

#define SENSOR_CHAR_UUID \
"12345678-1234-1234-1234-123456789001"

NimBLECharacteristic *sensorCharacteristic;

const unsigned long SEND_INTERVAL = 50;

unsigned long lastSend = 0;


// =====================================================
// MOTOR PWM
// =====================================================

void setMotorPWM(uint8_t pwm)
{
  ledcWrite(
    MOTOR_PIN,
    pwm
  );
}


// =====================================================
// MOTOR MODE NAME
// =====================================================

const char* motorModeName()
{
  switch (motorMode)
  {
    case MOTOR_OFF:
      return "OFF";

    case MOTOR_CONTINUOUS:
      return "CONTINUOUS";

    case MOTOR_PULSE:
      return "PULSE";

    case MOTOR_HARMONIC:
      return "HARMONIC";

    default:
      return "UNKNOWN";
  }
}


// =====================================================
// MOTOR MODE CHANGE
// =====================================================

void nextMotorMode()
{
  setMotorPWM(0);


  if (motorMode == MOTOR_OFF)
  {
    motorMode = MOTOR_CONTINUOUS;
  }

  else if (motorMode == MOTOR_CONTINUOUS)
  {
    motorMode = MOTOR_PULSE;
  }

  else if (motorMode == MOTOR_PULSE)
  {
    motorMode = MOTOR_HARMONIC;
  }

  else
  {
    motorMode = MOTOR_OFF;
  }


  modeChangeTime = millis();

  modeGapActive = true;

  pulseMotorOn = true;

  pulseTimer = millis();

  harmonicStartTime = millis();


  Serial.print("MOTOR MODE: ");

  Serial.println(
    motorModeName()
  );
}


// =====================================================
// BUTTON
// =====================================================

void updateMotorButton()
{
  bool currentButtonState =
    digitalRead(
      MODE_BUTTON_PIN
    );


  if (
    previousButtonState == HIGH &&
    currentButtonState == LOW
  )
  {
    if (
      millis() - lastButtonPress >
      BUTTON_DEBOUNCE
    )
    {
      lastButtonPress = millis();

      nextMotorMode();
    }
  }


  previousButtonState =
    currentButtonState;
}


// =====================================================
// MOTOR CONTROL
// =====================================================

void updateMotor()
{
  unsigned long now = millis();


  // MODE CHANGE GAP
  if (modeGapActive)
  {
    setMotorPWM(0);


    if (
      now - modeChangeTime <
      MODE_CHANGE_GAP
    )
    {
      return;
    }


    modeGapActive = false;

    pulseTimer = now;

    pulseMotorOn = true;

    harmonicStartTime = now;
  }


  // OFF
  if (motorMode == MOTOR_OFF)
  {
    setMotorPWM(0);

    return;
  }


  // CONTINUOUS
  if (motorMode == MOTOR_CONTINUOUS)
  {
    setMotorPWM(
      CONTINUOUS_PWM
    );

    return;
  }


  // PULSE
  if (motorMode == MOTOR_PULSE)
  {
    if (pulseMotorOn)
    {
      setMotorPWM(
        PULSE_PWM
      );


      if (
        now - pulseTimer >=
        PULSE_ON_TIME
      )
      {
        pulseMotorOn = false;

        pulseTimer = now;
      }
    }

    else
    {
      setMotorPWM(0);


      if (
        now - pulseTimer >=
        PULSE_OFF_TIME
      )
      {
        pulseMotorOn = true;

        pulseTimer = now;
      }
    }


    return;
  }


  // HARMONIC
  if (motorMode == MOTOR_HARMONIC)
  {
    float phase =
      (
        (now - harmonicStartTime) %
        HARMONIC_PERIOD
      )
      /
      (float)HARMONIC_PERIOD;


    float wave =
      (
        1.0f -
        cos(
          2.0f *
          PI *
          phase
        )
      )
      /
      2.0f;


    float pwmValue =
      HARMONIC_MIN_PWM +
      wave *
      (
        HARMONIC_MAX_PWM -
        HARMONIC_MIN_PWM
      );


    setMotorPWM(
      (uint8_t)pwmValue
    );

    return;
  }
}


// =====================================================
// HEATER
// =====================================================

void updateHeater()
{
  if (!temperatureValid)
  {
    heaterOn = false;

    digitalWrite(
      HEATER_PIN,
      LOW
    );

    return;
  }


  if (
    latestTemperature >=
    HEATER_HARD_CUTOFF
  )
  {
    heaterOn = false;

    digitalWrite(
      HEATER_PIN,
      LOW
    );

    return;
  }


  if (
    latestTemperature <=
    HEATER_ON_TEMP
  )
  {
    heaterOn = true;
  }

  else if (
    latestTemperature >=
    HEATER_OFF_TEMP
  )
  {
    heaterOn = false;
  }


  digitalWrite(
    HEATER_PIN,
    heaterOn ? HIGH : LOW
  );
}


// =====================================================
// MPU REGISTER WRITE
// =====================================================

bool writeMPURegister(
  uint8_t reg,
  uint8_t value
)
{
  Wire.beginTransmission(
    MPU_ADDR
  );

  Wire.write(reg);

  Wire.write(value);


  return (
    Wire.endTransmission() == 0
  );
}


// =====================================================
// MPU REGISTER READ
// =====================================================

uint8_t readMPURegister(
  uint8_t reg
)
{
  Wire.beginTransmission(
    MPU_ADDR
  );

  Wire.write(reg);


  if (
    Wire.endTransmission(false) != 0
  )
  {
    return 0xFF;
  }


  Wire.requestFrom(
    MPU_ADDR,
    1
  );


  if (
    Wire.available() < 1
  )
  {
    return 0xFF;
  }


  return Wire.read();
}


// =====================================================
// MPU INITIALIZATION
// =====================================================

bool initializeMPU()
{
  Serial.println();

  Serial.println(
    "Initializing MPU6500..."
  );


  Wire.begin(
    SDA_PIN,
    SCL_PIN
  );


  Wire.setClock(
    400000
  );


  delay(150);


  uint8_t whoAmI =
    readMPURegister(
      MPU_WHO_AM_I
    );


  Serial.print(
    "WHO_AM_I = 0x"
  );

  Serial.println(
    whoAmI,
    HEX
  );


  if (
    whoAmI != MPU6500_ID
  )
  {
    Serial.println(
      "WARNING: Expected MPU6500 ID 0x70"
    );
  }


  if (
    !writeMPURegister(
      MPU_PWR_MGMT_1,
      0x00
    )
  )
  {
    Serial.println(
      "ERROR: MPU6500 not responding"
    );

    return false;
  }


  delay(100);


  // Accelerometer +/-2g
  writeMPURegister(
    MPU_ACCEL_CONFIG,
    0x00
  );


  // Gyroscope +/-250 deg/sec
  writeMPURegister(
    MPU_GYRO_CONFIG,
    0x00
  );


  // Gyro low-pass
  writeMPURegister(
    MPU_CONFIG,
    0x03
  );


  // Accelerometer low-pass
  // Approx 10 Hz bandwidth
  writeMPURegister(
    MPU_ACCEL_CONFIG2,
    0x05
  );


  delay(100);


  Serial.println(
    "MPU6500 initialized."
  );


  Serial.println(
    "Accel vibration filtering enabled."
  );


  return true;
}


// =====================================================
// READ MPU
// =====================================================

bool readMPU()
{
  Wire.beginTransmission(
    MPU_ADDR
  );

  Wire.write(
    MPU_ACCEL_XOUT_H
  );


  if (
    Wire.endTransmission(false) != 0
  )
  {
    return false;
  }


  uint8_t received =
    Wire.requestFrom(
      MPU_ADDR,
      14,
      true
    );


  if (received != 14)
  {
    return false;
  }


  rawAx =
    ((int16_t)Wire.read() << 8) |
    Wire.read();

  rawAy =
    ((int16_t)Wire.read() << 8) |
    Wire.read();

  rawAz =
    ((int16_t)Wire.read() << 8) |
    Wire.read();


  // Skip internal temperature
  Wire.read();
  Wire.read();


  rawGx =
    ((int16_t)Wire.read() << 8) |
    Wire.read();

  rawGy =
    ((int16_t)Wire.read() << 8) |
    Wire.read();

  rawGz =
    ((int16_t)Wire.read() << 8) |
    Wire.read();


  return true;
}


// =====================================================
// ACTUATORS OFF
// =====================================================

void disableActuators()
{
  setMotorPWM(0);

  heaterOn = false;

  digitalWrite(
    HEATER_PIN,
    LOW
  );
}


// =====================================================
// CORRECTED SENSOR FUSION INITIALIZATION
// =====================================================

void initializeFusionFromReference()
{
  float rx = referenceAx;
  float ry = referenceAy;
  float rz = referenceAz;


  float mag =
    sqrt(
      rx * rx +
      ry * ry +
      rz * rz
    );


  if (mag < 0.1f)
  {
    q0 = 1.0f;
    q1 = 0.0f;
    q2 = 0.0f;
    q3 = 0.0f;

    return;
  }


  rx /= mag;
  ry /= mag;
  rz /= mag;


  // ==================================================
  // CORRECTED INITIAL QUATERNION
  //
  // Estimated gravity now starts aligned with the
  // calibrated upright reference.
  //
  // This avoids the temporary ~180 degree startup.
  // ==================================================

  if (rz > -0.999f)
  {
    q0 =
      sqrt(
        (1.0f + rz) *
        0.5f
      );


    float denom =
      2.0f *
      q0;


    // CORRECTED SIGNS
    q1 =
      ry /
      denom;

    q2 =
      -rx /
      denom;

    q3 =
      0.0f;
  }

  else
  {
    q0 = 0.0f;
    q1 = 1.0f;
    q2 = 0.0f;
    q3 = 0.0f;
  }


  // Normalize quaternion
  float norm =
    sqrt(
      q0*q0 +
      q1*q1 +
      q2*q2 +
      q3*q3
    );


  if (norm > 0.00001f)
  {
    q0 /= norm;
    q1 /= norm;
    q2 /= norm;
    q3 /= norm;
  }


  integralFBx = 0.0f;
  integralFBy = 0.0f;
  integralFBz = 0.0f;


  filteredAx =
    referenceAx;

  filteredAy =
    referenceAy;

  filteredAz =
    referenceAz;


  accelFilterInitialized =
    true;


  latestBodyAngle =
    0.0f;


  lastFusionMicros =
    micros();
}


// =====================================================
// MPU CALIBRATION
// =====================================================

void calibrateMPU()
{
  calibrationRunning = true;

  disableActuators();


  Serial.println();

  Serial.println(
    "======================================"
  );

  Serial.println(
    " HER COMFORT MPU6500 CALIBRATION"
  );

  Serial.println(
    "======================================"
  );


  Serial.println();

  Serial.println(
    "Wear belt normally."
  );

  Serial.println(
    "Sit or stand STRAIGHT."
  );

  Serial.println(
    "Keep completely STILL."
  );


  Serial.println();

  Serial.println(
    "Starting in 3 seconds..."
  );


  delay(3000);


  double axSum = 0;
  double aySum = 0;
  double azSum = 0;

  double gxSum = 0;
  double gySum = 0;
  double gzSum = 0;


  for (
    int i = 0;
    i < 100;
    i++
  )
  {
    readMPU();

    delay(5);
  }


  int validSamples = 0;


  while (
    validSamples <
    CALIBRATION_SAMPLES
  )
  {
    disableActuators();


    if (!readMPU())
    {
      continue;
    }


    float ax =
      rawAx /
      ACCEL_SCALE;

    float ay =
      rawAy /
      ACCEL_SCALE;

    float az =
      rawAz /
      ACCEL_SCALE;


    float gx =
      rawGx /
      GYRO_SCALE;

    float gy =
      rawGy /
      GYRO_SCALE;

    float gz =
      rawGz /
      GYRO_SCALE;


    axSum += ax;
    aySum += ay;
    azSum += az;

    gxSum += gx;
    gySum += gy;
    gzSum += gz;


    validSamples++;


    if (
      validSamples % 100 == 0
    )
    {
      Serial.print(
        "Calibration: "
      );

      Serial.print(
        validSamples / 10
      );

      Serial.println("%");
    }


    delay(4);
  }


  gyroBiasX =
    gxSum /
    validSamples;

  gyroBiasY =
    gySum /
    validSamples;

  gyroBiasZ =
    gzSum /
    validSamples;


  referenceAx =
    axSum /
    validSamples;

  referenceAy =
    aySum /
    validSamples;

  referenceAz =
    azSum /
    validSamples;


  float magnitude =
    sqrt(
      referenceAx * referenceAx +
      referenceAy * referenceAy +
      referenceAz * referenceAz
    );


  if (magnitude > 0.1f)
  {
    referenceAx /= magnitude;
    referenceAy /= magnitude;
    referenceAz /= magnitude;
  }


  initializeFusionFromReference();


  Serial.println();

  Serial.println(
    "CALIBRATION COMPLETE"
  );


  Serial.print(
    "Gyro bias: "
  );

  Serial.print(
    gyroBiasX,
    3
  );

  Serial.print(", ");

  Serial.print(
    gyroBiasY,
    3
  );

  Serial.print(", ");

  Serial.println(
    gyroBiasZ,
    3
  );


  Serial.print(
    "Upright reference: "
  );

  Serial.print(
    referenceAx,
    3
  );

  Serial.print(", ");

  Serial.print(
    referenceAy,
    3
  );

  Serial.print(", ");

  Serial.println(
    referenceAz,
    3
  );


  Serial.println(
    "Sensor fusion initialized."
  );


  calibrationRunning = false;
}


// =====================================================
// ACCEL LOW PASS FILTER
// =====================================================

void updateAccelLowPass(
  float ax,
  float ay,
  float az,
  float dt
)
{
  if (!accelFilterInitialized)
  {
    filteredAx = ax;
    filteredAy = ay;
    filteredAz = az;

    accelFilterInitialized = true;

    return;
  }


  float rc =
    1.0f /
    (
      2.0f *
      PI *
      ACCEL_LPF_CUTOFF_HZ
    );


  float alpha =
    dt /
    (
      rc +
      dt
    );


  alpha =
    constrain(
      alpha,
      0.0f,
      1.0f
    );


  filteredAx +=
    alpha *
    (
      ax -
      filteredAx
    );


  filteredAy +=
    alpha *
    (
      ay -
      filteredAy
    );


  filteredAz +=
    alpha *
    (
      az -
      filteredAz
    );
}


// =====================================================
// MAHONY SENSOR FUSION
// =====================================================
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
void loop()
{
  // EMG
  updateEMG();


  // BUTTON
  updateMotorButton();


  // MOTOR
  updateMotor();


  // TEMPERATURE
  updateTemperature();


  // HEATER
  updateHeater();


  // MPU
  updatePosition();


  // ==================================================
  // BLE + SERIAL
  // ==================================================

  if (
    millis() -
    lastSend >=
    SEND_INTERVAL
  )
  {
    lastSend =
      millis();


    String data = "{";


    // Temperature
    data +=
      "\"temperature\":";

    data +=
      String(
        latestTemperature,
        2
      );


    // Position
    data +=
      ",\"position\":\"";

    data +=
      positionName(
        currentPosition
      );

    data +=
      "\"";


    // Body Angle
    data +=
      ",\"bodyAngle\":";

    data +=
      String(
        latestBodyAngle,
        1
      );


    // Motor
    data +=
      ",\"motorMode\":\"";

    data +=
      motorModeName();

    data +=
      "\"";


    // Heater
    data +=
      ",\"heater\":\"";

    data +=
      heaterOn ?
      "ON" :
      "OFF";

    data +=
      "\"";


    // EMG
    data +=
      ",\"emg\":";

    data +=
      String(
        latestEMG
      );


    data +=
      "}";


    sensorCharacteristic->setValue(
      data.c_str()
    );


    sensorCharacteristic->notify();


    Serial.println(
      data
    );
  }
}

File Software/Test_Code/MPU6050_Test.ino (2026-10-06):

/*
  ================================================================
  HER COMFORT — MPU6500 POSITION & POSTURE ENGINEERING TEST FIRMWARE
  ================================================================
  Board:   Seeed Studio XIAO ESP32-C6
  IMU:     MPU6500 (I2C, addr 0x68)
  Pins:    SDA = D4 / GPIO22   SCL = D5 / GPIO23

  PURPOSE
  -------
  This is a CALIBRATION / VALIDATION tool, not a finished product.
  It answers one engineering question: can a single waist-mounted
  MPU6500 reliably separate Lying / Upright / Moving / Still, and
  can trunk-tilt posture be tracked over time?

  It does NOT measure spinal pressure, disc load, or any clinical
  quantity. All posture output is a relative, engineer-defined
  "Posture Load" indicator only — see calculatePostureLoad().

  DATA FLOW
  ---------
  MPU6500
    -> readMPU()                 raw accel/gyro registers
    -> calibrateGyro()           one-time zero-offset removal
    -> low-pass on accel         light smoothing on ax/ay/az
    -> calculateOrientation()    complementary filter -> pitch/roll
    -> updateMotionState()       gyro/accel magnitude -> moving/still
    -> classifyPosition()        candidate Lying/Upright/Moving/Still
    -> confirmPosition()         time-confirmed state (anti-flicker)
    -> classifyPosture()         deviation from calibrated neutral
    -> updatePostureTimer()      duration + hysteresis on posture
    -> calculatePostureLoad()    tilt x duration x movement factor
    -> printSerialData()         CSV line + event logs over Serial

  SERIAL COMMAND PROTOCOL (send as text line ending with \n)
  ------------------------------------------------------------
    CAL_GYRO         re-run gyro zero-offset calibration (keep still)
    CAL_NEUTRAL       calibrate neutral posture (hold correct posture)
    RESET             reset all duration timers and posture load
    START              begin logging/test run
    STOP                pause logging/test run
    MARK:SITTING        write an activity marker line to Serial
    MARK:STANDING
    MARK:LYING
    MARK:WALKING
    MARK:FORWARD_BEND
    MARK:LEAN_LEFT
    MARK:LEAN_RIGHT

  These are the same commands the companion web test-interface sends
  when you press its buttons.

  !!! ALL THRESHOLDS BELOW ARE PLACEHOLDERS !!!
  They are starting points only. Use the CSV log + MARK: events to
  compare known ground-truth activities against sensor output, then
  tune the CONFIGURATION block until states track reliably for you.
*/

#include <Wire.h>

// ================================================================
// PIN / DEVICE CONFIGURATION
// ================================================================
#define SDA_PIN 22          // D4
#define SCL_PIN 23          // D5
#define MPU_ADDR 0x68

// MPU6500 registers (compatible with MPU60x0 map)
#define REG_PWR_MGMT_1   0x6B
#define REG_SMPLRT_DIV   0x19
#define REG_CONFIG       0x1A
#define REG_GYRO_CONFIG  0x1B
#define REG_ACCEL_CONFIG 0x1C
#define REG_ACCEL_XOUT_H 0x3B
#define REG_WHO_AM_I     0x75

// Sensitivity for configured full-scale ranges.
// Accel is configured to +-2g -> 16384 LSB/g.
// Gyro is configured to +-250 dps -> 131 LSB/(deg/s), as specified.
const float ACCEL_LSB_PER_G   = 16384.0f;
const float GYRO_LSB_PER_DPS  = 131.0f;

// ================================================================
// CONFIGURATION — ALL VALUES BELOW ARE PLACEHOLDERS.
// They must be tuned against real recorded data (see MARK: events
// and the CSV log). None of these are medically validated.
// ================================================================

// --- Sensor fusion ---
const float COMPLEMENTARY_ALPHA = 0.98f;   // weight on gyro-integrated angle vs accel angle
const float ACCEL_LPF_ALPHA     = 0.20f;   // low-pass smoothing applied to raw accel (0=no update,1=no filtering)
const float GYRO_DEADBAND_DPS   = 1.5f;    // below this, treat gyro axis as zero (removes drift/noise)

// --- Motion / stillness detection ---
const float MOTION_GYRO_THRESHOLD_DPS = 20.0f;  // gyro magnitude above this => "moving"
const float MOTION_ACCEL_THRESHOLD_G  = 0.25f;  // |accel_mag - 1g| above this => "moving"
const float STILL_ACCEL_BAND_G        = 0.08f;  // |accel_mag - 1g| within this AND low gyro => "still"

// --- Position (Lying vs Upright) via total tilt from vertical ---
// tiltMag = sqrt(pitch^2 + roll^2), degrees, 0 = perfectly upright reference
const float UPRIGHT_TILT_MAX_DEG = 35.0f;   // tiltMag below this => candidate UPRIGHT
const float LYING_TILT_MIN_DEG   = 55.0f;   // tiltMag above this => candidate LYING
// Between UPRIGHT_TILT_MAX_DEG and LYING_TILT_MIN_DEG is an intentional
// "ambiguous band" — in that zone position holds its last confirmed value
// rather than guessing, to avoid flicker on real bodies bending/sitting.

const uint32_t POSITION_CONFIRM_MS = 3000; // candidate must hold for this long before becoming confirmed

// --- Posture (deviation from calibrated neutral) ---
const float GOOD_ANGLE_LIMIT_DEG  = 8.0f;   // deviation below this => GOOD
const float MILD_ANGLE_LIMIT_DEG  = 18.0f;  // deviation below this (and above GOOD) => MILD_LEAN
                                             // deviation above this => NEEDS_ATTENTION candidate
const uint32_t POSTURE_CONFIRM_MS = 3000;   // candidate posture state must hold this long to confirm
const uint32_t POSTURE_WARNING_MS = 60000;  // NEEDS_ATTENTION must persist this long before a warning log fires

// --- Posture Load scoring (engineering indicator only, NOT medical) ---
// PostureLoad accumulates while posture is MILD_LEAN or NEEDS_ATTENTION,
// scaled by tilt severity, and is suppressed while the user is MOVING
// (a transient bend while walking should not count as "sustained load").
const float POSTURE_LOAD_LOW_MAX      = 30.0f;
const float POSTURE_LOAD_MODERATE_MAX = 100.0f;
// above POSTURE_LOAD_MODERATE_MAX => HIGH

// --- Calibration sampling ---
const uint16_t GYRO_CAL_SAMPLES    = 400;  // ~2s at 200Hz, device must be still
const uint16_t NEUTRAL_CAL_SAMPLES = 200;  // ~2s at 200Hz, device in correct neutral posture

// --- Loop timing ---
const uint32_t SAMPLE_INTERVAL_MS = 5;    // ~200 Hz sensor read
const uint32_t PRINT_INTERVAL_MS  = 50;   // ~20 Hz serial CSV output (keep graphs smooth, avoid flooding)

// ================================================================
// STATE ENUMS
// ================================================================
enum PositionState { POS_UNKNOWN, POS_UPRIGHT, POS_LYING, POS_MOVING, POS_STILL };
enum PostureState  { POST_UNKNOWN, POST_GOOD, POST_MILD_LEAN, POST_NEEDS_ATTENTION };
enum LeanDirection { LEAN_NONE, LEAN_FORWARD, LEAN_BACKWARD, LEAN_LEFT, LEAN_RIGHT };

const char* positionName(PositionState s) {
  switch (s) {
    case POS_UPRIGHT: return "UPRIGHT";
    case POS_LYING:    return "LYING";
    case POS_MOVING:   return "MOVING";
    case POS_STILL:    return "STILL";
    default:           return "UNKNOWN";
  }
}
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

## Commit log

2026-10-01 HerComfort mechanical design
    [HerComfort_Refined.SLDPRT, HerComfort_Refined.step]
2026-10-01 Add HerComfort product images
    Uploaded front, rear, top, bottom, side, isometric, inner belt, EMG contact, USB/button, front module, rear comfort pad, and combined product views for documentation and README
2026-10-06 Updated PCB Files
    [pcb-B_Cu.gbr, pcb-B_Mask.gbr, pcb-B_Paste.gbr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]
2026-10-06 Rename Mechanical and PCB folders
    [HerComfort_Refined.SLDPRT, HerComfort_Refined.step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]
2026-10-06 Added BOM
    [BOM.xlsx]
2026-10-06 Added ESP32 Codes
